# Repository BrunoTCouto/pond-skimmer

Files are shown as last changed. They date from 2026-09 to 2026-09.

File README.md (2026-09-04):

<h1 align="center">pond-skimmer</h1>

<p align="center">
  Skimmer de lago impresso em 3D para cano de PVC de esgoto de <b>150 mm</b>,<br>
  com <b>barreira de peixes de 3 mm</b>, cesto removível e vazão de verdade.<br>
  100% gerado por script paramétrico em Python — sem CAD manual.
</p>

<p align="center">
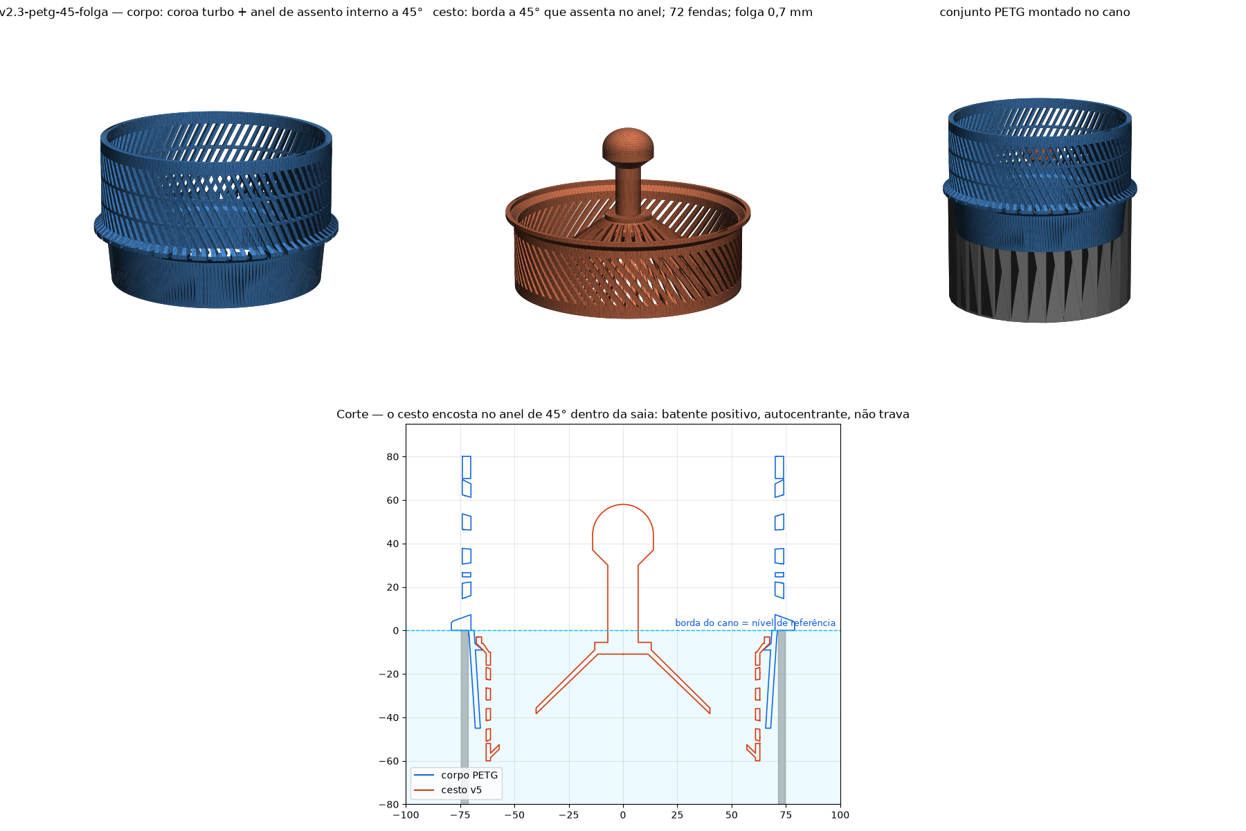
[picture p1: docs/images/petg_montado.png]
v2.3: corpo PETG + cesto montados no cano
  <br>
  <sub><b>v2.3</b> (atual) — corpo com anel de assento interno a 45° e cesto de 72 fendas. z = 0 é a borda do cano. Figuras geradas dos STLs por <code>tools/render.py</code>.</sub>
</p>

<p align="center">
  <a href="#-começando">Começando</a> ·
  <a href="#-como-funciona">Como funciona</a> ·
  <a href="#-peças-e-versões">Peças e versões</a> ·
  <a href="#-impressão">Impressão</a> ·
  <a href="#-instalação-e-uso">Instalação</a> ·
  <a href="#-a-física-em-um-parágrafo">A física</a> ·
  <a href="#-modificar-e-regenerar">Modificar</a> ·
  <a href="docs/DISCOVERY.md">Discovery</a> ·
  <a href="CHANGELOG.md">Changelog</a>
</p>

---

## 🚀 Começando

Quer só imprimir? Pegue o **par** de uma pasta em `stl/` — corpo e cesto de
versões diferentes **não** encaixam.

| Quero… | Pasta | Arquivos | Material |
|---|---|---|---|
| a versão definitiva (atual) | [`stl/v2.3-petg-45-folga/`](stl/v2.3-petg-45-folga/) | `corpo150_v2.3.stl` + `cesto150_v2.3.stl` | PETG |
| reproduzir o que está no lago hoje | [`stl/v1.0-instalado/`](stl/v1.0-instalado/) | `corpo150_turbo.stl` + `cesto150_v3.stl` | ABS + PLA |

Configurações de impressão em [Impressão](#-impressão). Nenhuma peça usa
suporte.

## 💧 Como funciona

O cano de 150 mm é o dreno do lago: o nível da água fica na borda dele. O
skimmer encaixa **por dentro** do cano e apoia um aro na borda — nada sobe o
nível por construção. Acima da borda fica uma coroa ranhurada; dentro do
cano, um cesto removível.

```
                    ┌───────── coroa: 80 fendas × 3 mm, 80 mm ─────────┐
                    │  ~55% do perímetro aberto = 250 mm de vertedouro │
  lago ──► fendas ──┼──► cai no cesto ──► fendas de 2 mm ──► cano ──► bomba
                    │     (parede + fundo em cone)                     │
  ═══════ nível ≈ borda + 3 cm ═════════════════════════════════════════
                    └── aro apoiado na borda · saia Ø136→142 centraliza ──┘
```

- **Peixe**: o vão de 3 mm da coroa barra tudo que não seja alevino. O que
  passa (≤ 3 mm) cai num cesto de fendas de **2 mm** — fica preso **vivo**
  até a limpeza, em vez de seguir pro rotor da bomba.
- **Folhas e sujeira**: ficam na coroa (fendas diagonais soltam detrito) ou
  no cesto. Limpar = puxar o cesto pelo botão.
- **Nível**: definido pelo perímetro aberto na linha d'água, e só por ele.
  Com a bomba do lago (~2–3 L/s) o nível fica ~3 cm acima da borda, contra
  ~2 cm do cano nu. Ver [a física](#-a-física-em-um-parágrafo).

## 📦 Peças e versões

Os STLs vivem em **pastas por versão — uma por pedido, imutáveis**; cada
pasta é um conjunto fechado, com README próprio. Visão geral em [`stl/README.md`](stl/README.md), detalhes em
[`CHANGELOG.md`](CHANGELOG.md), e o que está fisicamente instalado (com
SHA-256) em [`docs/IMPRESSO.md`](docs/IMPRESSO.md).

| Versão | Corpo | Cesto | Como o cesto se apoia | Status |
|---|---|---|---|---|
| **v2.3** `stl/v2.3-petg-45-folga/` | coroa turbo + **anel de assento a 45°** interno | borda a 45°, **72 fendas** de 2 mm (43% aberta), colar com 0,7 mm de folga | borda encosta no anel: batente positivo, autocentra, não trava | **atual** — imprimir em PETG |
| v2.0 → v2.2 | idem (v2.2: prateleira reta) | 36 → 72 fendas; colar 0,2–0,6 → 0,7 mm | — | superadas; ver `stl/README.md` |
| **v1.0** `stl/v1.0-instalado/` | coroa turbo (chanfro no furo da saia) | **v3**: 3 pilares com abinha, 36 fendas | abinhas no topo da coroa | **no lago** (ABS + PLA), tag `v1.0-instalado` |
| v1.0 alternativa | — | **v4**: sem pilares | cone de 13° no chanfro da saia (trava, tipo cone Morse) | encaixa no corpo v1.0; não impresso |

<p align="center">
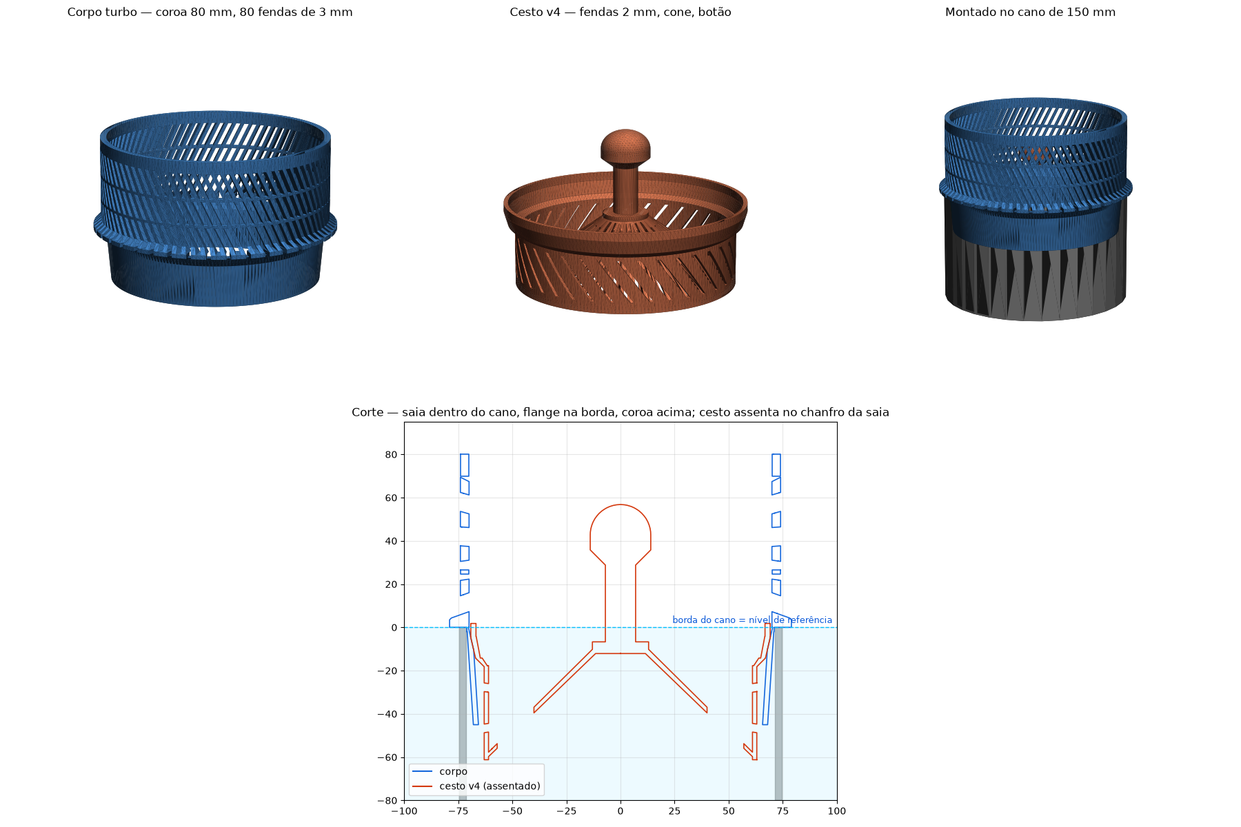
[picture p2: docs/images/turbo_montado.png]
v1.0 montado
  <br>
  <sub>v1.0 (o que está no lago): corpo turbo com chanfro no furo e cesto v4 no corte.</sub>
</p>

<p align="center">
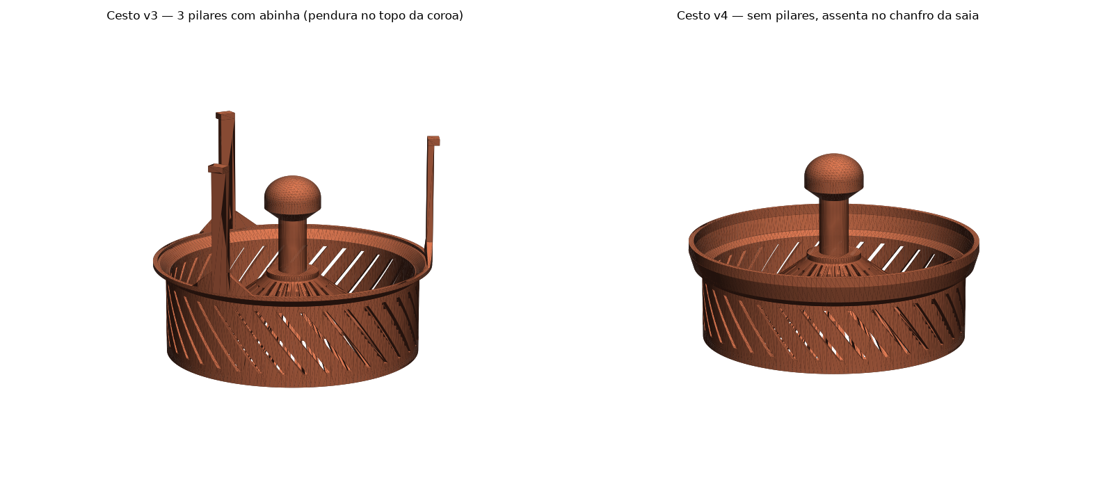
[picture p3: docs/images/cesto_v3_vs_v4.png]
cesto v3 vs v4
  <br>
  <sub>v1.0: cesto v3 (pilares com abinha, o que está impresso) e v4 (assenta no chanfro).</sub>
</p>

**O que é igual em todas**: coroa de 80 mm com 80 fendas de 3 mm inclinadas
a 20°, costelas de ~2,4 mm, parede de 4 mm, 2 anéis de travamento; saia
cônica Ø136→142 que entra no cano e centraliza; aro Ø158 apoiado na borda
com canais de entrada no nível da borda; cesto com fundo em cone "raios de
sol" (72 fendas de 2 mm) e botão central pra puxar.

## 🖨️ Impressão

| Peça | Orientação | Brim | Suporte | Perímetros | Notas |
|---|---|---|---|---|---|
| Corpo (qualquer versão) | **de cabeça pra baixo** — topo da coroa na mesa | 5 mm | **não** | ≥ 3 | 80 torres finas de 2,4 mm: câmara fechada ajuda; os anéis de travamento amarram as torres. Na v2.x o anel de assento vira um balanço de 45° |
| Cesto (todas as versões) | **em pé** — fundo na mesa | 5 mm | **não** | 6 | cone a 45°, botão com cone de 45° sob a cabeça; abinhas do v3 têm 2,7 mm de balanço |

**Material**: PETG é o ideal (água + sol). ABS também é definitivo. PLA
aguenta semanas/meses em água de lago, mas é quebradiço — serve de
provisório. Se o slicer oferecer suporte automático, **recuse**: ele planta
árvores de 8 cm dentro do cesto pra segurar balanços de 2 mm.

## 🔧 Instalação e uso

1. **Corpo**: desce com a saia dentro do cano até o aro apoiar na borda. Sem
   fixação — a saia (Ø142 na borda) centraliza com 0,5–1,5 mm de folga.
2. **Cesto**: desce pelo centro da coroa. v2.x assenta a borda de 45° no anel
   interno (autocentra); v3 apoia as 3 abinhas no topo da coroa, em qualquer
   ângulo.
3. **Limpeza**: puxa o cesto pelo botão, sacode, volta. A coroa se limpa
   passando a mão; o corpo sai do cano só de levantar.
4. **Nível subindo com o tempo** = fendas entupindo. Com 30% tapadas o nível
   sobe ~25%.

## 📐 A física em um parágrafo

O cano nu é um vertedouro de 450 mm de perímetro. Tudo que se põe na boca
dele reduz o perímetro **aberto na linha d'água**, e é só isso que define o
nível: `Q ≈ 1,7 · L · h^1,5`. A primeira versão tinha fendas de 3 mm a cada
12 mm mais uma banda no cesto — sobraram 85 mm de vertedouro e a água subiu
mais de 55 mm, passando por cima. **Altura da coroa não ajuda** (fenda seca é
parede) e **grade é pior que fenda** (paga barra nas duas direções). O que
ajuda: costela mais fina (80 fendas, 2,4 mm) e tirar o que estiver atrás das
fendas (a banda do cesto). Resultado: ~250 mm de vertedouro.

<p align="center">
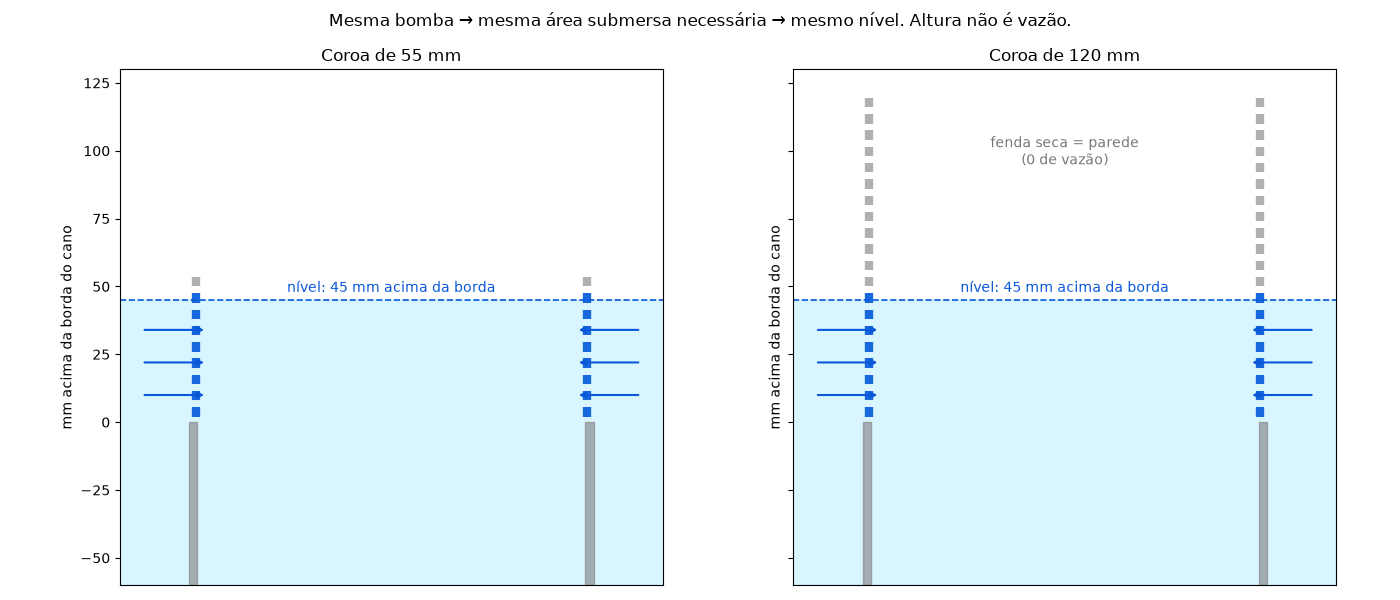
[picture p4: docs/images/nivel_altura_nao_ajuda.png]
altura não é vazão
  
</p>

A história completa, com os erros, está em [`docs/DISCOVERY.md`](docs/DISCOVERY.md).

## 🛠️ Modificar e regenerar

Tudo é gerado por [`scripts/skimmer150.py`](scripts/skimmer150.py) com
[`manifold3d`](https://github.com/elalish/manifold) + `trimesh`. As
dimensões são constantes no topo do arquivo; STL nunca é editado à mão.

```bash
python3 -m venv venv && ./venv/bin/pip install -r requirements.txt
./venv/bin/python scripts/skimmer150.py           # gera TODAS as pastas de stl/ (tabela VERSIONS no fim do script)
./venv/bin/python tools/check_fit.py stl/v2.3-petg-45-folga/corpo150_v2.3.stl stl/v2.3-petg-45-folga/cesto150_v2.3.stl
./venv/bin/python tools/render.py                 # figuras de docs/images
```

[`tools/check_fit.py`](tools/check_fit.py) é o que roda antes de qualquer
STL sair do repo: peça única e estanque, colisão cesto × corpo assentado e
durante a inserção, altura em que o cesto assenta, perímetro aberto na linha
d'água e um corte em PNG.

Regras que custaram impressões (detalhes no Discovery):

- `Manifold.cylinder(h, r_base, r_topo)` — cone invertido foi o bug mais repetido.
- `CrossSection` sempre **anti-horário**; horário vira furo e o manifold sai vazio.
- Sólidos que só se tocam num plano não se fundem: sempre um anel de solda.
- Corte inclinado precisa ir fundo pra cobrir a parede curva — e depois ser
  **confinado** ao anel da parede, senão morde o cone do fundo.
- Anel apoiado em pilares = anel no ar = não imprime.
- Toda peça nova passa pelo `check_fit.py` contra o corpo do **par**.

## 🗂️ Layout do repo

```
scripts/skimmer150.py     fonte de verdade; tabela VERSIONS = uma pasta por versão
stl/<versão>/             STLs gerados + README do conjunto (pastas imutáveis)
tools/check_fit.py        verificação de encaixe e vazão
tools/render.py           figuras de docs/images a partir dos STLs
docs/DISCOVERY.md         diário: hidráulica, peixes, CSG, impressão
docs/IMPRESSO.md          o que está no lago, com SHA-256
CHANGELOG.md              versões
CLAUDE.md                 regras pra sessões de Claude Code
```

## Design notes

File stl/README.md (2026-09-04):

# STLs por versão

**Uma pasta por pedido, e pasta é imutável.** Cada mudança — por menor que
seja — vira uma pasta nova; a anterior fica exatamente como estava. Assim
qualquer STL que já foi baixado ou impresso continua rastreável. A versão
mais recente é a que o README principal mostra.

Corpo e cesto de uma pasta encaixam **entre si**. Não misture pastas.

| Pasta | O que mudou | Corpo | Cesto | Status |
|---|---|---|---|---|
| [`v1.0-instalado/`](v1.0-instalado/) | corpo turbo (80 fendas, coroa 80 mm) + cesto v3 em pilares | `corpo150_turbo.stl` | `cesto150_v3.stl` (`cesto150_v4.stl` também encaixa) | **no lago** — ABS + PLA |
| [`v2.0-petg/`](v2.0-petg/) | primeiro conjunto PETG: anel de assento a 45° dentro da saia; cesto sem pilares | `corpo150_v2.0.stl` | `cesto150_v2.0.stl` — 36 fendas, colar Ø136 | superada |
| [`v2.1-petg-72fendas/`](v2.1-petg-72fendas/) | fendas da parede do cesto 36 → **72** | `corpo150_v2.1.stl` | `cesto150_v2.1.stl` — 72 fendas, colar Ø136 | superada |
| [`v2.2-petg-prateleira/`](v2.2-petg-prateleira/) | assento vira prateleira reta de 2,2 mm com 60° embaixo; colar com folga 0,7 mm | `corpo150_v2.2.stl` | `cesto150_v2.2.stl` — colar reto Ø135 | superada (dono preferiu o 45°) |
| [`v2.3-petg-45-folga/`](v2.3-petg-45-folga/) | volta o anel de 45°, mantém a folga de 0,7 mm no colar | `corpo150_v2.3.stl` | `cesto150_v2.3.stl` — 72 fendas, colar Ø135 | **atual** — imprimir em PETG |

Comum a todas: coroa de 80 mm com 80 fendas de 3 mm, saia Ø136→142 dentro do
cano, aro na borda; cesto com fendas de 2 mm, fundo em cone e botão.

Como nasce cada arquivo: `python scripts/skimmer150.py` gera **todas** as
pastas a partir da tabela `VERSIONS` no fim do script (ou
`python scripts/skimmer150.py v2.3-petg-45-folga` pra uma só). STL nunca é
editado à mão. Detalhes de cada versão no [CHANGELOG](../CHANGELOG.md); o que
está fisicamente instalado (com SHA-256) em [docs/IMPRESSO.md](../docs/IMPRESSO.md).

Cada pasta tem um `preview.png` (3 vistas 3D + corte com o cesto assentado),
gerado por `python tools/render.py` — é o que se olha antes de imprimir.

Antes de imprimir, confira o par:

```bash
python tools/check_fit.py stl/<pasta>/corpo*.stl stl/<pasta>/cesto*.stl
```

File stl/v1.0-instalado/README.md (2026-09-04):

# v1.0 — instalado no lago

| Arquivo | Peça | Material | Notas |
|---|---|---|---|
| `corpo150_turbo.stl` | corpo | **ABS**, impresso 2026-09-03 | coroa 80 mm, 80 fendas × 3 mm a 20°, parede 4 mm, 2 anéis, saia Ø136→142 com chanfro interno de 13°. **Não alterar**: é a referência de encaixe dos cestos desta pasta |
| `cesto150_v3.stl` | cesto | **PLA** (provisório), impresso 2026-09-04 | 3 pilares 8×3 mm com abinha no topo da coroa; 36 fendas × 2 mm; fundo em cone; botão |
| `cesto150_v4.stl` | cesto (alternativa) | não impresso | assenta no chanfro de 13° da saia, nada acima da borda; o cone raso trava — funciona, mas pede um puxão pra sair |

Impressão: corpo de cabeça pra baixo com brim; cestos em pé com brim; sem
suporte; ≥3 perímetros (6 no cesto).

SHA-256 dos arquivos impressos em [docs/IMPRESSO.md](../../docs/IMPRESSO.md).
Tag git: `v1.0-instalado`.

## Preview

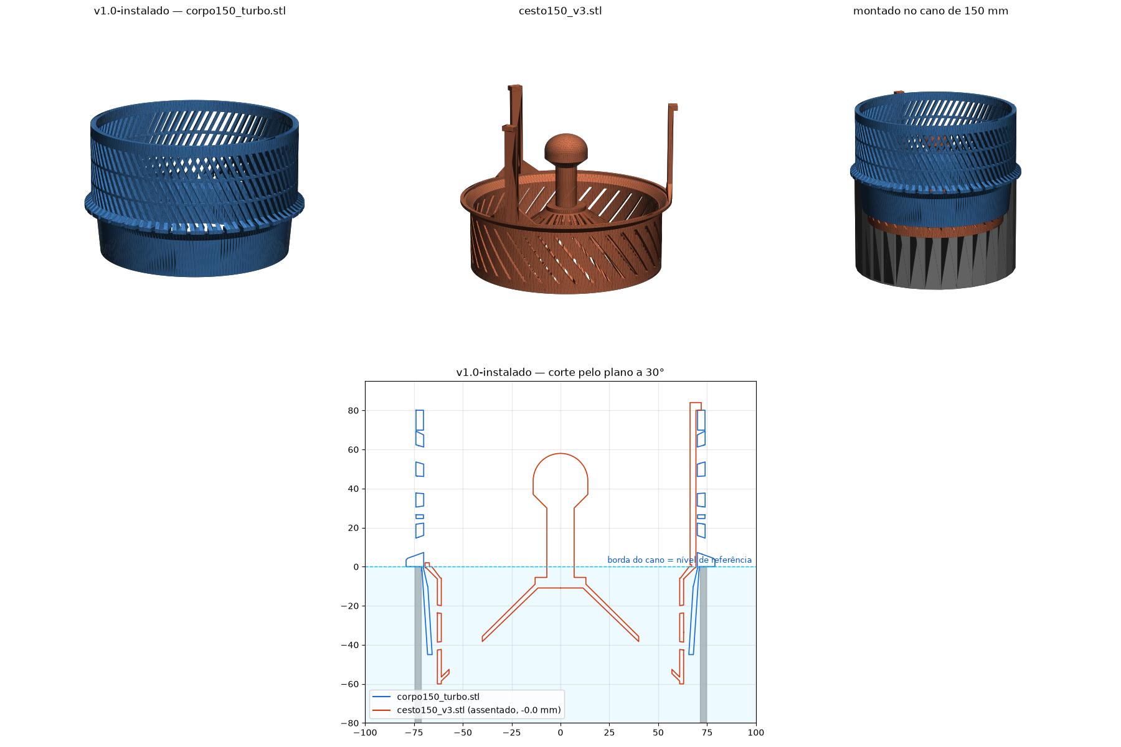
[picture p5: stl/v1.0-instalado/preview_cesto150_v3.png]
corpo + cesto v3


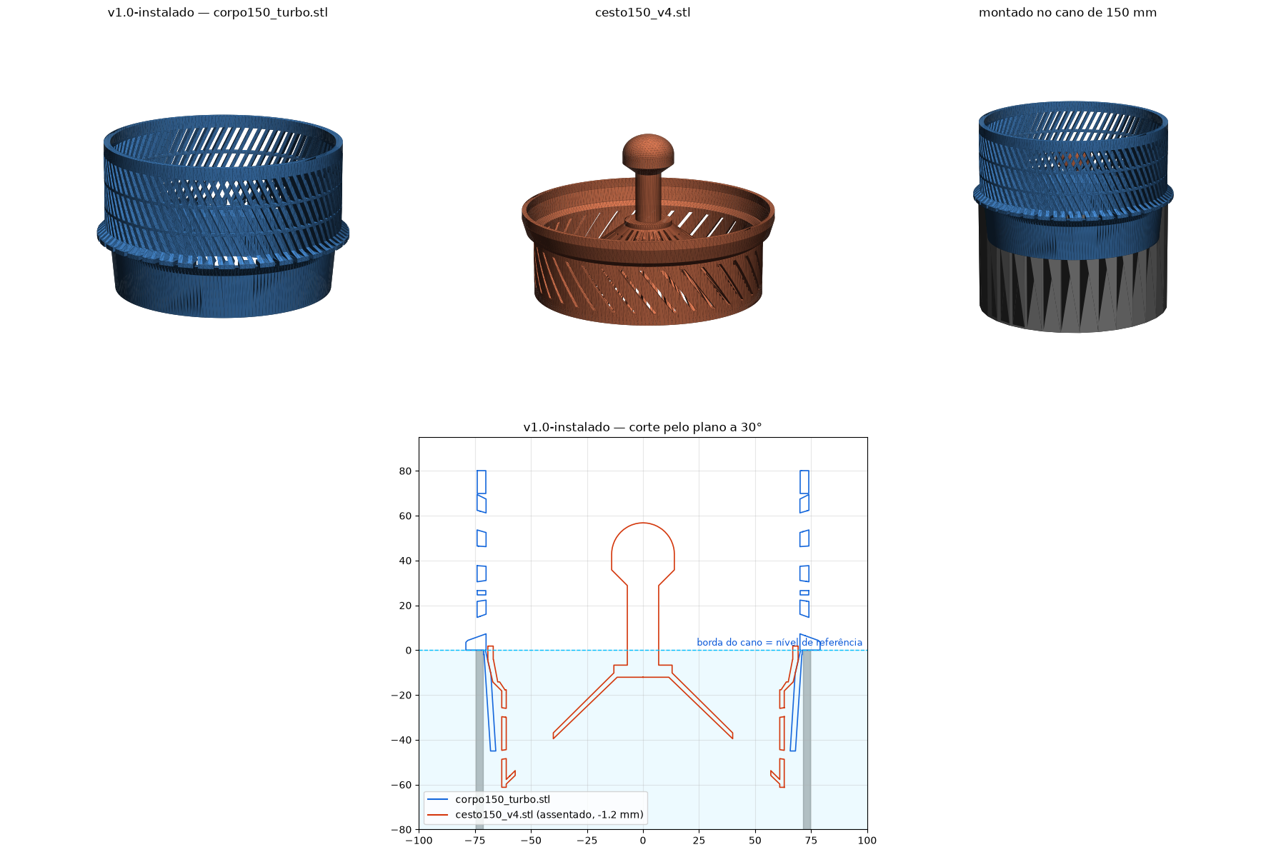
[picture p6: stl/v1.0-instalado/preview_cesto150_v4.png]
corpo + cesto v4


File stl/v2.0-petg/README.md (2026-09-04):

# v2.0-petg — primeiro conjunto PETG (superada)

Pedido: "fazer todos os modelos novos, preparar tudo pro PETG" — corpo com
suporte interno pro cesto em vez de pilares.

| Arquivo | Peça | Notas |
|---|---|---|
| `corpo150_v2.0.stl` | corpo | coroa turbo da v1.0 + **anel de assento a 45°** dentro da saia (z −9 a −4,8; r 64,5 → 68,7); sem o chanfro do furo |
| `cesto150_v2.0.stl` | cesto | borda a 45° que assenta no anel; colar Ø136 (folga de só 0,2–0,6 mm no furo — corrigido na v2.2+); **36 fendas** de 2 mm; fundo em cone; botão |

Só encaixam um no outro. Superada por [`v2.1-petg-72fendas`](../v2.1-petg-72fendas/).

## Preview

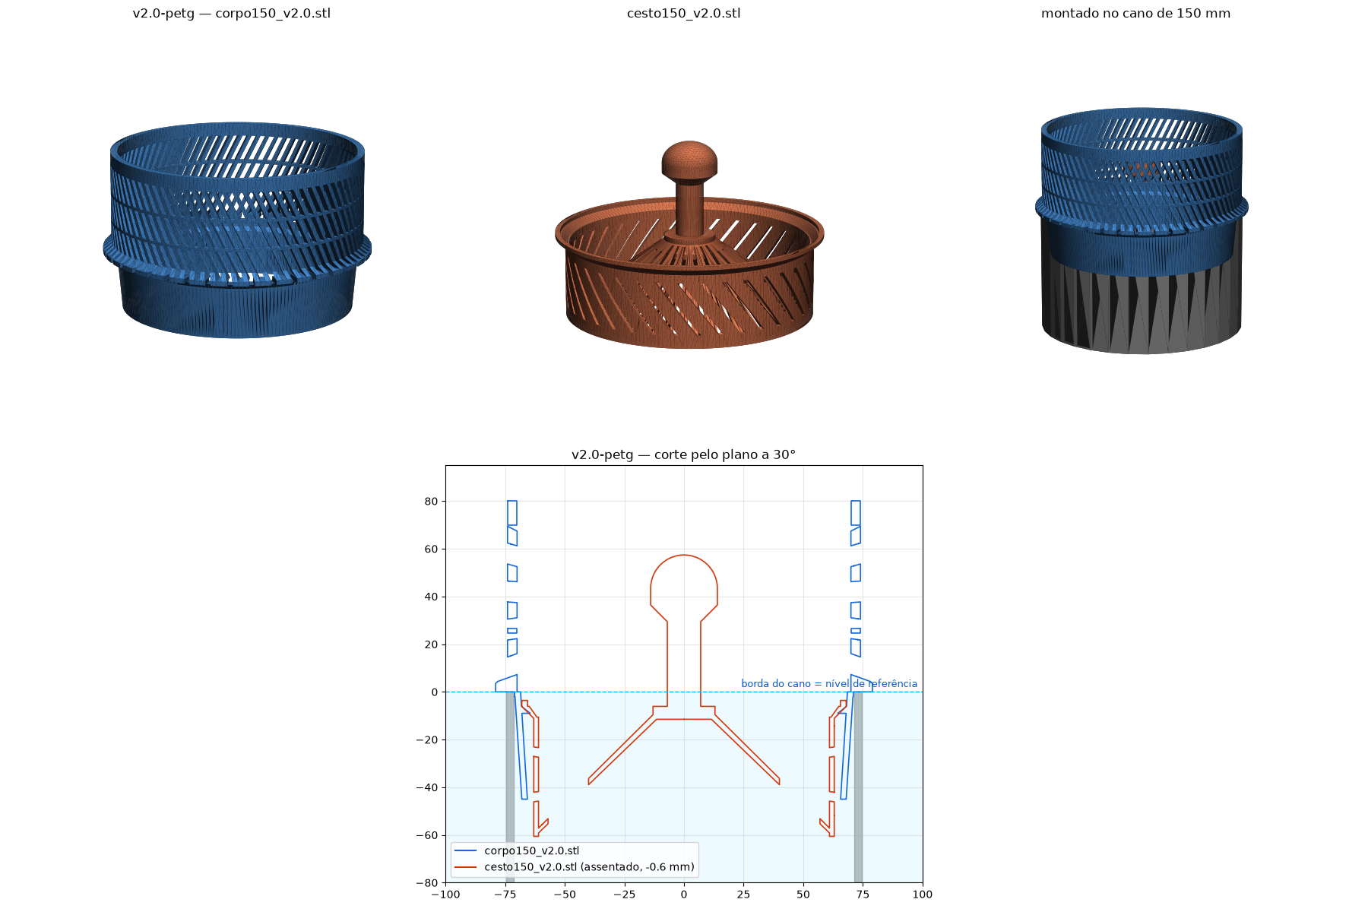
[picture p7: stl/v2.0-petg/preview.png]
preview


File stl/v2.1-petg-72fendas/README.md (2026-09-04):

# v2.1-petg-72fendas — mais vãos na lateral do cesto (superada)

Pedido: "dá pra aumentar a quantidade de vãos na lateral do cesto, igual
fizemos no corpo?"

| Arquivo | Peça | Notas |
|---|---|---|
| `corpo150_v2.1.stl` | corpo | idêntico ao da v2.0 (anel de assento a 45°) |
| `cesto150_v2.1.stl` | cesto | fendas da parede **36 → 72** (costela ~3 mm, 43% aberta em vez de 21%); colar Ø136; resto igual à v2.0 |

Só encaixam um no outro. Superada por [`v2.2-petg-prateleira`](../v2.2-petg-prateleira/).

## Preview

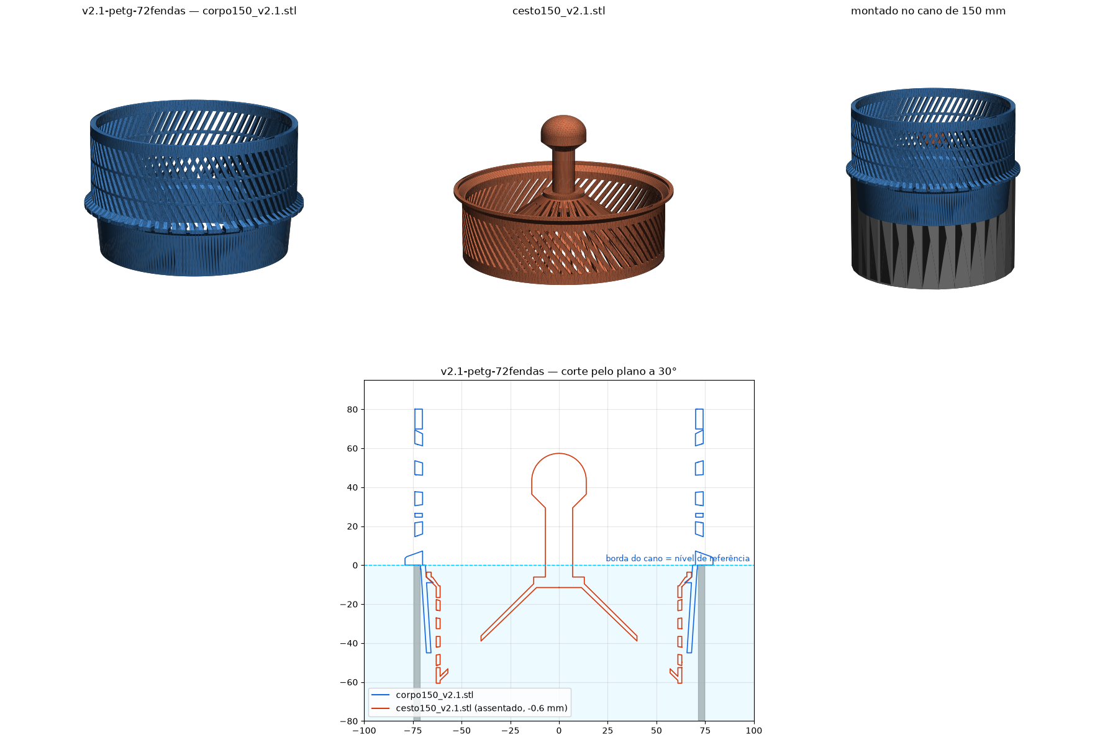
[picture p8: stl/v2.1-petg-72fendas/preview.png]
preview


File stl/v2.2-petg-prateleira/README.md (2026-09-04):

# v2.2-petg-prateleira — assento em prateleira reta (superada)

Pedido: "chanfro de suporte mais fácil de imprimir — parte de baixo sobe
inclinado, parte de cima reta". Também abriu a folga do colar.

| Arquivo | Peça | Notas |
|---|---|---|
| `corpo150_v2.2.stl` | corpo | coroa turbo + **prateleira** dentro da saia: topo reto em z −6 (2,2 mm), parte de baixo a 60° até a parede |
| `cesto150_v2.2.stl` | cesto | colar reto Ø135 (folga 0,7 mm) que apoia na prateleira; 72 fendas |

Funciona e imprime (o topo reto vira um balanço de uma camada de 2,2 mm na
impressão invertida). O dono preferiu voltar ao anel de 45°, que na
impressão de ponta-cabeça já era "base inclinada, topo reto".
Superada por [`v2.3-petg-45-folga`](../v2.3-petg-45-folga/).

## Preview

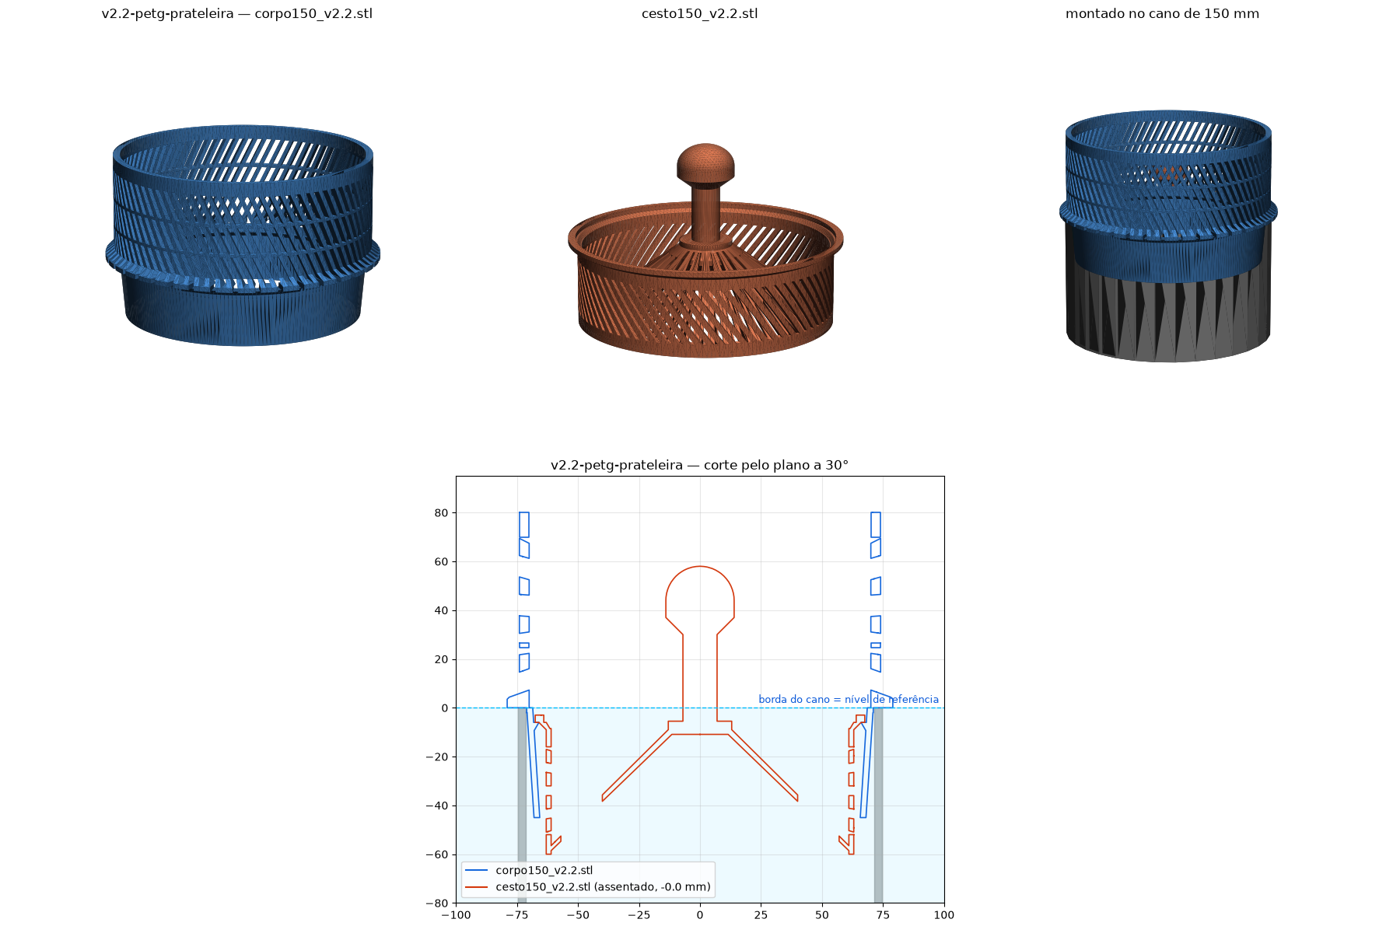
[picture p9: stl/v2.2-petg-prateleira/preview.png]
preview


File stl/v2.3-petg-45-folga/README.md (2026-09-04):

# v2.3-petg-45-folga — conjunto PETG atual

Pedido: "a versão de antes tava boa — fecha a versão boa". Anel de 45° de
volta, mantendo a folga de 0,7 mm no colar que a v2.2 trouxe.

| Arquivo | Peça | Notas |
|---|---|---|
| `corpo150_v2.3.stl` | corpo | coroa turbo (80 fendas × 3 mm, 80 mm, parede 4 mm, 2 anéis) + **anel de assento a 45°** dentro da saia (z −9 a −4,8; r 64,5 → 68,7); sem o chanfro do furo |
| `cesto150_v2.3.stl` | cesto | borda a 45° que assenta no anel (batente positivo, autocentrante, não trava); colar Ø135 com **0,7 mm de folga**; topo em z −3 (nada acima da borda do cano); **72 fendas** de 2 mm na parede (43% aberta); fundo em cone com 72 fendas; botão |

**Só encaixam um no outro.** O cesto não tem apoio no corpo da v1.0.

Impressão (PETG, Bambu P1S): corpo de cabeça pra baixo com brim — o anel de
assento vira um balanço de 45°; cesto em pé com brim, 6 perímetros; suporte
**desligado** nos dois.

Verificado: 1 corpo cada, 0 colisões assentado e em +20/+50 mm, assenta no
anel com 0,4 mm de acomodação, 52% do perímetro aberto (240 mm de vertedouro).

Ao instalar: atualizar `docs/IMPRESSO.md` e criar a tag `v2.3-instalado`.

## Preview

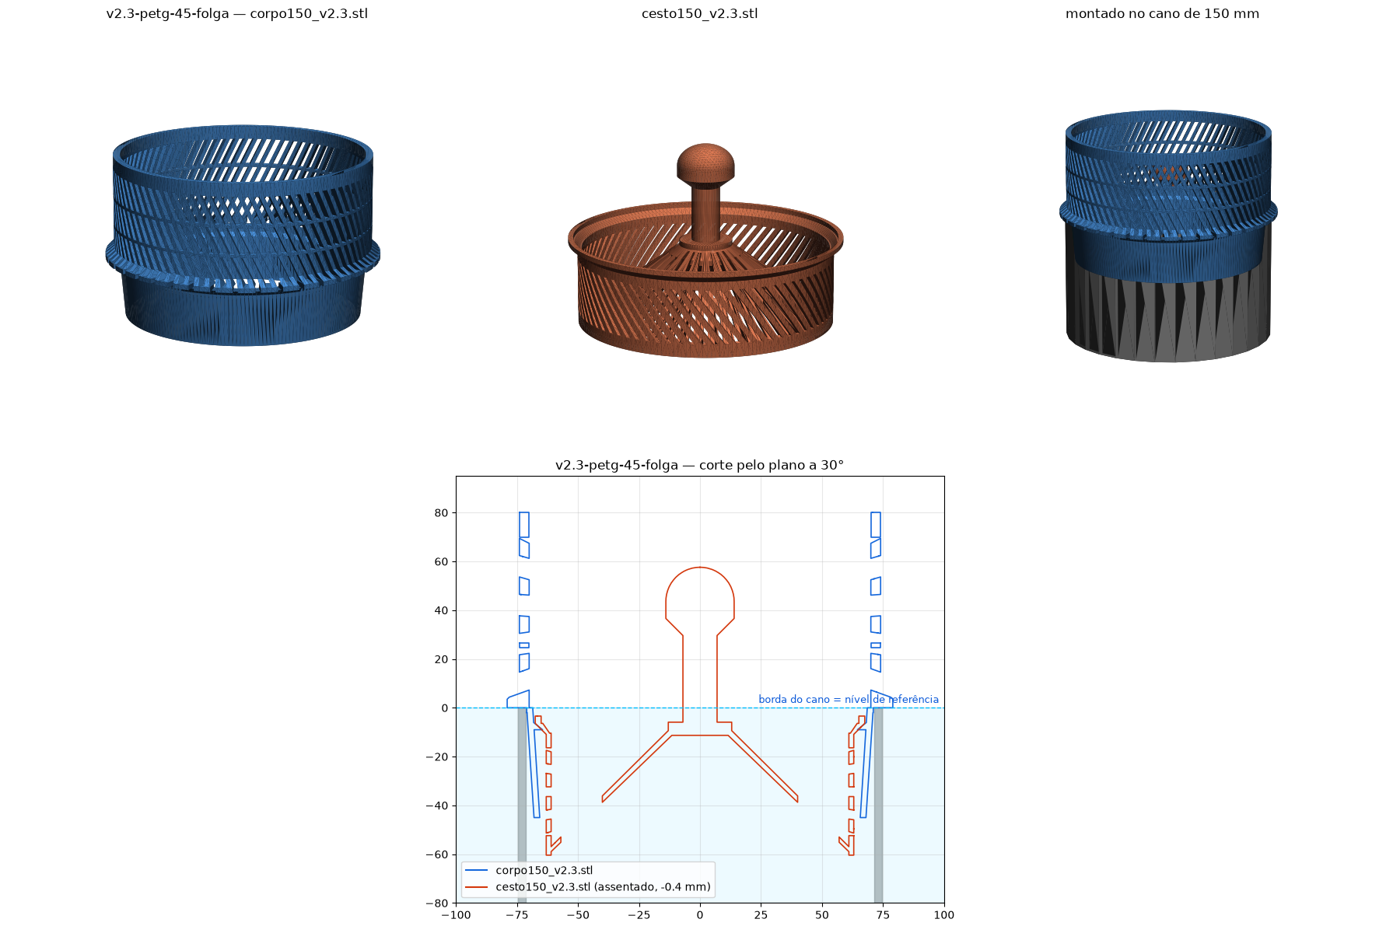
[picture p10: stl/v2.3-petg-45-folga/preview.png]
preview


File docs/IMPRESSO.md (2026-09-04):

# O que está instalado no lago

Nota de referência: se um dia precisar reimprimir **exatamente** o que está lá,
ou saber se um STL novo ainda encaixa, é isto aqui. Tag git: `v1.0-instalado`.

| Peça | Arquivo | Material | Impresso em | SHA-256 do STL |
|---|---|---|---|---|
| Corpo | `stl/v1.0-instalado/corpo150_turbo.stl` | ABS (Bambu P1S, 0.20 mm Strength, 6 paredes) | 2026-09-03 | `074b1c6b4e48bdd89bbbf02e807f4427c8351a55aac63afd9d6b18c8bbf55f60` |
| Cesto | `stl/v1.0-instalado/cesto150_v3.stl` | PLA genérico (provisório até o PETG) | 2026-09-04 | `d25568b3e3782798a476feef0245259df0fc708bc4a71bad1f325fb9b63d41ca` |

Conferir se o arquivo atual ainda é o impresso:

```bash
shasum -a 256 stl/v1.0-instalado/corpo150_turbo.stl stl/v1.0-instalado/cesto150_v3.stl
```

Se o hash mudou, o script foi alterado e o STL **não** é mais o que está no
lago — o par de referência continua sendo o hash acima (recuperável com
`git show v1.0-instalado:stl/v1.0-instalado/corpo150_turbo.stl > corpo_impresso.stl`).

## Observações de campo

- Cano: PVC esgoto, externo 149–151, interno 143–145, parede 3 mm.
- A saia (Ø142 na borda) entra com folga; a flange apoia na borda.
- Cesto v3 apoia pelas 3 abinhas no topo da coroa, em qualquer ângulo.
- Plano: substituir **as duas peças** pelo conjunto PETG atual
  (`stl/v2.3-petg-45-folga/`). Aí este arquivo deve ser atualizado (hashes
  novos) e uma tag `v2.3-instalado` criada.

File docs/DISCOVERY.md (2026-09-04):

# Discovery — o que aprendemos fazendo o skimmer

Diário das decisões, erros e medições do projeto, na ordem em que aconteceram.
Serve de memória pra quem (humano ou Claude) for mexer de novo.

## 1. Ponto de partida

- Arquivo: `Skimmer.3mf` do Bambu Studio, 2 plates (`Outside.STEP`,
  `Inside.STEP`), só malhas (150k/200k faces). Sem CAD paramétrico → não dá
  pra "mudar uma medida"; a saída foi remodelar do zero em Python.
- Medidas do original (extraídas da malha, eixo Y): luva Ø110 interna
  (~120 mm), cone Ø110→140 (50 mm), cesta ranhurada Ø140/146 (80 mm). Cesto
  interno Ø139,8 (folga 0,1 mm) com fendas que giram pra regular a abertura.
- Restrições do dono: cano de **150 mm** e **o nível da água não pode subir**
  da borda do cano. O original é um "pescoço" de 130 mm em cima do cano —
  incompatível com a segunda restrição.

## 2. Medidas do cano

- Externo "150" medido; interno **143–145**; parede **3 mm** (PVC esgoto).
- Saia de centragem: Ø136 na ponta → **Ø142 na borda**. Nunca pode chegar em
  143: se a saia calçar antes da flange apoiar, a peça fica suspensa e os
  canais de entrada sobem junto.

## 3. Hidráulica (a lição cara)

O cano nu é um vertedouro de **450 mm** de perímetro. Qualquer coisa que se
coloque em cima dele reduz o perímetro aberto na **linha d'água** — e é só
isso que define o nível:

    Q ≈ 1,7 · L · h^1,5     (vertedouro; L = perímetro aberto, h = lâmina)

- v1: fenda de 3 mm a cada 12 mm (25% aberto) × banda do cesto (79%) → L ≈
  **85 mm**. Com a bomba do lago (estimada em 2–3 L/s pela foto), h > 55 mm
  → passou por cima da coroa.
altura não é vazão

- Coisas que **não** mudam o nível: altura da coroa (fenda seca é parede),
  grade em vez de fenda (paga barra nas duas direções: 3×3 com barra de 2 =
  36% aberto, pior que fenda), formato do furo.
- Coisas que mudam: costela mais fina (limite de impressão ~2,4 mm), vão
  maior (passa peixe), perímetro maior.
- turbo: 80 fendas × 3 mm, costela 2,4 mm, sem banda → 54% → L ≈ **248 mm**.
  Estimativa: h ≈ 28 mm a 2 L/s, 37 mm a 3 L/s (cano nu: 19 / 25 mm).
- Entupimento: com 30% das fendas tapadas h sobe ~25%. Limpar a coroa faz
  parte.
- Qualquer barreira de 3 mm sempre pede alguns mm de lâmina a mais que o
  cano aberto — é o preço da barreira de peixes.

## 4. Peixes

- O que barra peixe é a **menor dimensão** do vão, não a inclinação.
- Fendas diagonais valem por outro motivo: soltam detrito (nada fica
  entalado em pé) e são ~15% mais compridas → deu pra estreitar 5→3 mm sem
  perder área.
- Cesto com fendas de 2,5 mm atrás de uma coroa de 3 mm retém só a faixa
  2,5–3: quase nada. Um alevino que passou pela coroa seguia pro cano → bomba.
  **Regra: fendas do cesto (2 mm) menores que o gate da coroa (3 mm)** —
  tudo que entra fica no cesto, vivo, até a limpeza.
- Peixe no cesto não asfixia (água corrente), mas apanha da queda d'água e
  seca se a bomba desligar. Não é lugar de peixe.

## 5. CSG com manifold3d — pegadinhas que custaram iterações

1. `Manifold.cylinder(h, r_baixo, r_topo)`: a ordem é **base → topo**. Cone
   invertido aconteceu **três vezes** (saia, transição do cesto, e num
   terceiro cone). Sintoma: peça em vários corpos ou dimensões espelhadas.
2. Dois sólidos que se tocam só num plano (z=0) **não viram um corpo**:
   `split()` do trimesh mostra 2 shells. Sempre um "anel de solda" com
   sobreposição volumétrica (ex.: `tube(71.5, 70.2, -2, 3.5)` entre saia e
   flange).
3. Corte inclinado (fenda diagonal) numa parede cilíndrica: a caixa reta
   deriva tangencialmente e precisa começar bem pra dentro (r=50–58) pra cobrir
   a parede curva nos extremos. Aí ela **morde** o que estiver dentro (o cone
   do fundo). Solução: `cortes ^ tube(anel da parede)`.
4. Chanfro embaixo da aba do cesto colidia com o topo da coroa. Flat-on-flat
   com balanço de ≤2,7 mm imprime bem; não vale chanfro.
5. Reforço triangular plano num furo redondo: as pontas passam do raio do
   furo (r 71,6 > 70). Clipar com `^ tube(69.3, ...)`.
6. Verificação que sempre roda antes de entregar: `split()` = 1 corpo;
   `contains()` do corpo sobre os vértices do cesto em 0/+20/+50 mm de
   inserção = 0; perímetro aberto amostrado em grade (θ, z) nas duas paredes
   em série; corte (r, z) plotado com o cano sobreposto.

## 6. Impressão

- Corpo: de cabeça pra baixo (topo da coroa na mesa) com chanfro de 45° entre
  coroa e flange pra não haver balanço horizontal. 80 torres de 2,4 × 4 mm:
  os 2 anéis de travamento existem pra amarrar as torres na impressão, não
  só pra rigidez.
- Cesto: em pé. Cone do fundo a 45°, botão com cone de 45° sob a cabeça.
- **Anel apoiado em 4 pilares = anel no ar** entre os pilares (~100 mm sem
  apoio). Não imprime; suporte em árvore de 8 cm dentro do cesto é ridículo.
  → v3: cada pilar termina na sua própria abinha; 3 pilares (assenta sem
  balançar, 5% de bloqueio).
- v4 elimina os pilares: o cesto assenta num cone de 13° que casa com o
  chanfro interno da saia (r 68 @ z-10 → 70,3 @ z0). Desce ~1,3 mm e trava
  com contato de área; nada acima da borda. Encaixa no corpo impresso, mas o
  cone raso **trava** (tan 13° < atrito → efeito cone Morse): sai com um puxão.
- Conjunto PETG (v2.0): o corpo ganha um **anel de assento a 45°** dentro da
  saia (fundo reto, face de cima a 45° subindo até o furo). Como o corpo
  imprime de ponta-cabeça, na impressão o anel cresce pra dentro a 45° e
  termina reto — "parte de baixo inclinada, topo reto", exatamente o que uma
  impressora gosta. O cesto v5 tem borda a 45° casada: autocentra, batente
  positivo, não trava; colar com 0,7 mm de folga no furo da saia (o primeiro
  rascunho tinha 0,2–0,6 mm — apertado demais pra PETG). Parede do v5 com 72
  fendas (43% aberta) em vez de 36. Só encaixa nesse corpo.
- Chegamos a trocar por uma prateleira reta de 2,2 mm com 60° embaixo; era
  equivalente, e o dono preferiu voltar ao 45° original.
- Pegadinha nova de CSG: polígono de `CrossSection` em sentido **horário** é
  lido como furo → o `revolve` sai vazio e a união inteira vira um manifold
  inválido (bbox `None`). Sempre CCW no plano (r, z).
- Materiais: ABS e PETG são definitivos em água. PLA dura semanas/meses (só
  amolece >55 °C), mas é quebradiço.
- Bambu Studio com suporte automático planta árvores pras abinhas de 2,7 mm.
  Deixar **desligado**.

## 7. Ambiente

- OpenSCAD não instalado; `manifold3d` + `trimesh` no venv resolvem tudo,
  inclusive booleans robustos e `section()` pra cortes.
- `trimesh.section` precisa de `scipy`, `shapely`, `networkx`, `rtree`;
  `proximity.signed_distance` é lento — `contains()` com amostragem `[::4]`
  basta.
- macOS não tem `timeout`.
- O sandbox do Claude Code barra `cp` para `~/Downloads` e SSH pro GitHub;
  entregar via SendUserFile e usar HTTPS (`gh auth`).
- O scratchpad é volátil: foi apagado uma vez e o script teve que ser
  reconstruído. **Por isso existe este repo.**

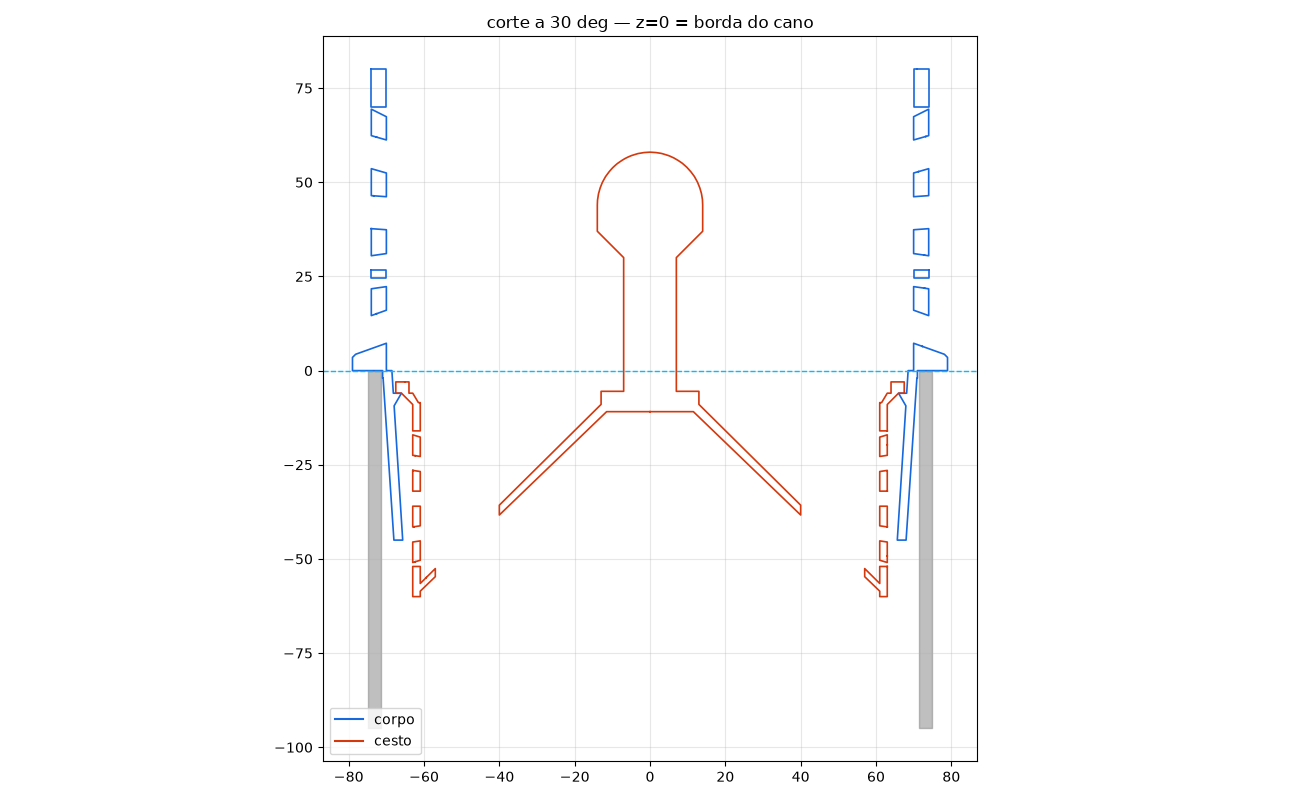
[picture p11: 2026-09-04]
docs/images/check_v2.2-petg-prateleira.png

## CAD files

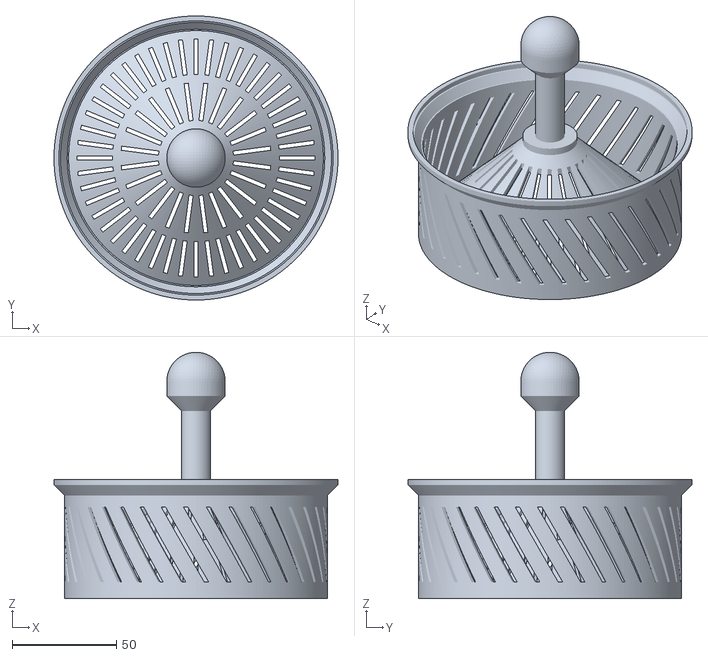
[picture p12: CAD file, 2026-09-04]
stl/v2.0-petg/cesto150_v2.0.stl
136.0 x 136.0 x 118.0

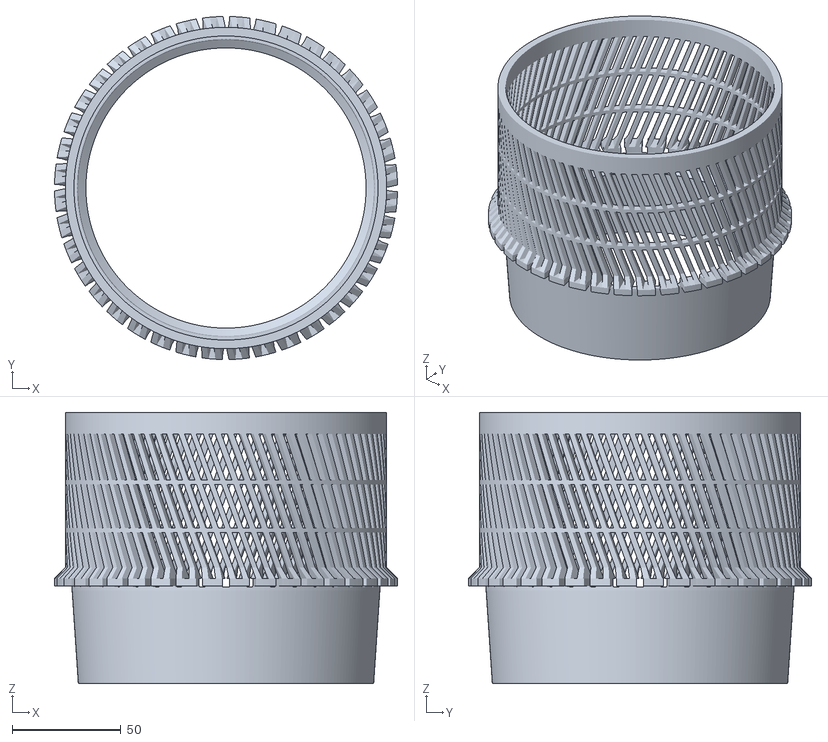
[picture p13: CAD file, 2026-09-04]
stl/v2.1-petg-72fendas/corpo150_v2.1.stl
158.0 x 158.0 x 125.0

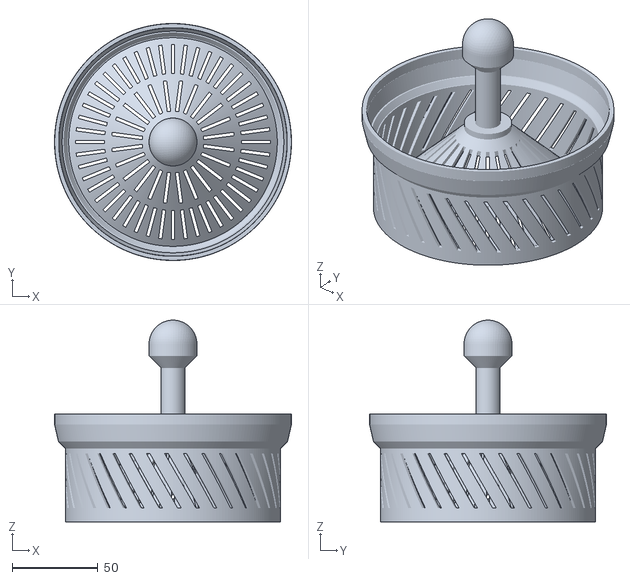
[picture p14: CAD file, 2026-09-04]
stl/v1.0-instalado/cesto150_v4.stl
138.6 x 138.6 x 118.0

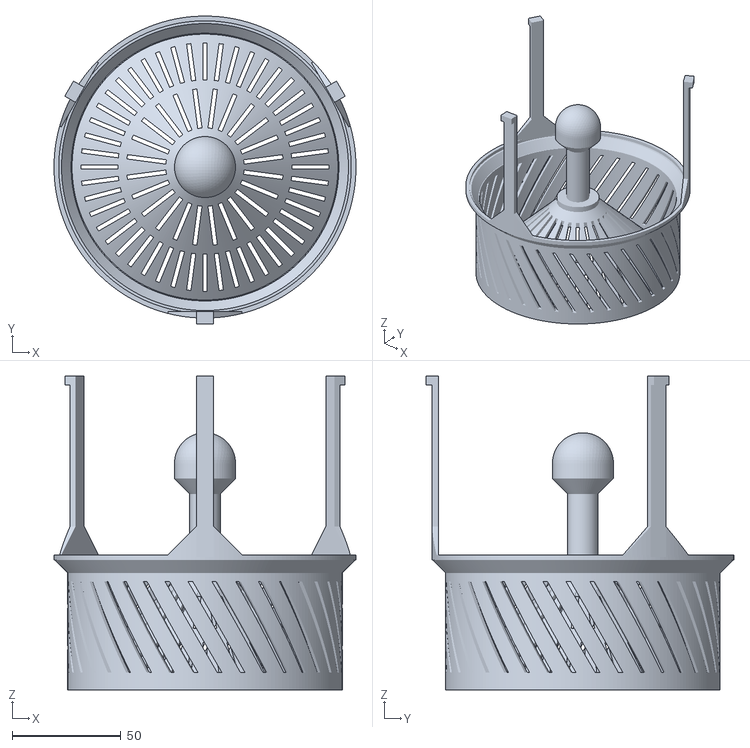
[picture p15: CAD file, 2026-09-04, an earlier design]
stl/v1.0-instalado/cesto150_v3.stl
138.6 x 141.3 x 144.0

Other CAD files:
stl/v2.2-petg-prateleira/cesto150_v2.2.stl
stl/v2.3-petg-45-folga/cesto150_v2.3.stl
stl/v2.1-petg-72fendas/cesto150_v2.1.stl
stl/v2.2-petg-prateleira/corpo150_v2.2.stl
stl/v1.0-instalado/corpo150_turbo.stl

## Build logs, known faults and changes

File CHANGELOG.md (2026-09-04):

# Changelog

Uma pasta em `stl/` por pedido do dono; **pasta é imutável** — mudança nova é
versão nova. Tags git marcam o que foi impresso e instalado; o que está
fisicamente no lago está em [docs/IMPRESSO.md](docs/IMPRESSO.md).

## v2.3-petg-45-folga — atual (não impressa ainda) — 2026-09-04

"A versão de antes tava boa — fecha a versão boa." Volta o anel de assento a
45° da v2.0/v2.1, mantendo a folga de 0,7 mm no colar que veio da v2.2.
`corpo150_v2.3.stl` + `cesto150_v2.3.stl` (72 fendas, colar Ø135).
Verificação: 1 corpo cada, 0 colisões em 0/+20/+50 mm, 0,4 mm de acomodação
no anel, 52% do perímetro aberto (240 mm de vertedouro equivalente).

## v2.2-petg-prateleira — 2026-09-04

"Chanfro de suporte mais fácil de imprimir: parte de baixo sobe inclinado,
parte de cima reta." Assento vira prateleira reta de 2,2 mm com 60° embaixo;
cesto com colar reto Ø135 (folga 0,7 mm — a v2.0/v2.1 tinham 0,2–0,6, apertado
pra PETG). Imprime; na orientação invertida é equivalente ao 45°. Superada.

## v2.1-petg-72fendas — 2026-09-04

"Dá pra aumentar a quantidade de vãos na lateral do cesto?" Fendas da parede
do cesto 36 → 72 (43% aberta, o dobro). Corpo igual à v2.0.

## v2.0-petg — 2026-09-04

"Fazer todos os modelos novos, preparar tudo pro PETG." Corpo com **anel de
assento a 45° dentro da saia** (z −9 a −4,8; r 64,5 → 68,7), sem o chanfro do
furo; cesto sem pilares, borda a 45° que assenta no anel, 36 fendas, colar
Ø136. Motivação: o cone de 13° do v4 trava (cone Morse); o anel de 45° é um
batente que autocentra e solta fácil.

## v1.0-instalado — tag `v1.0-instalado` — 2026-09-03/04

O que está no lago.

- `corpo150_turbo.stl` — ABS. Coroa 80 mm, 80 fendas de 3 mm a 20°, costelas
  ~2,4 mm, parede 4 mm, 2 anéis de travamento, canais na borda a cada 2
  fendas, saia Ø136→142 com chanfro interno de 13° no furo.
- `cesto150_v3.stl` — PLA (provisório). 3 pilares 8×3 com abinha no topo da
  coroa e reforço de 45° na base; 36 fendas de 2 mm; fundo em cone; botão.
- `cesto150_v4.stl` — também encaixa nesse corpo (assenta no chanfro de 13°;
  nunca impresso — o cone raso trava).

## v0 — original (superada, arquivos não preservados)

Coroa de 55 mm com 36 fendas de 3 mm + banda giratória no cesto. Impressa; a
água passou por cima (vertedouro equivalente ~85 mm). Lição em
`docs/DISCOVERY.md`.

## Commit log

2026-09-04 Pond skimmer for a 150 mm PVC pipe: parametric scripts, STLs and discovery log
    - scripts/skimmer150.py: printed corpo (turbo: 80 x 3 mm slots, 80 mm crown,
    bracing rings) + cesto v3 (posts, printed in PLA) + cesto v4 (bevel seat,
    for the PETG reprint)
    - scripts/skimmer150_v2.py: plan B "fish fence" around the pipe
    - tools/check_fit.py: body/collision/seating/open-perimeter check + section PNG
    - docs/DISCOVERY.md: hydraulics, fish gate, CSG pitfalls, print lessons
    - CLAUDE.md: working rules for future sessions
    [cesto150_v2.stl, cesto150_v3.stl, cesto150_v4.stl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]
2026-09-04 docs: schematic renders instead of the photo; tools/render.py regenerates them from the STLs
2026-09-04 v2.0 PETG set, versioned STL folders, changelog and installed-parts note; drop plan B
    - corpo150_petg: turbo crown + internal 45-deg seat ledge in the skirt (no bore bevel)
    - cesto150_v5: 45-deg flare seats on the ledge (positive stop, no self-lock),
    72 x 2 mm wall slots (43% open, 2x v3/v4), top at z -3
    - stl/ split into v1.0-instalado (printed: ABS corpo + PLA cesto v3, + v4) and
    v2.0-petg; READMEs per folder; script exports straight into them
    - CHANGELOG.md; docs/IMPRESSO.md pins the printed STLs by SHA-256
    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
    [cesto150_v2.stl, cesto150_v3.stl, cesto150_v4.stl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]
2026-09-04 docs: DISCOVERY — drop stale v2 reference, describe v4 self-lock and the v2.0 PETG seat
2026-09-04 v2.0: shelf seat (flat 2.2 mm top, 60-deg underside) + wider collar clearance; README polish
    - corpo150_petg: ledge is now a flat shelf at z -6 with a 60-deg underside,
    printable upside-down as a one-layer 2.2 mm overhang (like the v3 tabs)
    - cesto150_v5: flat collar underside rests on the shelf; collar OD 135
    (0.7 mm clearance to the skirt bore, was 0.2-0.6); seating drop 0.0 mm
    - CrossSection winding lesson (CW = hole = empty manifold) in DISCOVERY/CLAUDE.md
    - README rewritten: quick start, how it works, versions table, print table,
    physics, repo layout; figure titles updated
    [cesto150_v5.stl, corpo150_petg.stl]
2026-09-04 v2.0: back to the 45-deg seat ring (owner's call), keep the 0.7 mm collar clearance; README leads with the latest version
    [cesto150_v5.stl, corpo150_petg.stl]
2026-09-04 Immutable version folders: one per owner request (v2.0 .. v2.3), VERSIONS table in the script
    - scripts/skimmer150.py: build_corpo_petg(seat) / build_cesto_v5(seat, collar_r, n_fine)
    + frozen VERSIONS table; LATEST = v2.3-petg-45-folga; `skimmer150.py <folder>` builds one
    - stl/: v2.0-petg (45-deg seat, 36 slots), v2.1-petg-72fendas, v2.2-petg-prateleira
    (flat shelf), v2.3-petg-45-folga (current) — each with its own README; v1.0 untouched
    (hashes verified)
    - check_fit run on all four PETG pairs (0 collisions each); render.py follows LATEST
    - CHANGELOG per version; CLAUDE.md: folders are immutable, README always shows LATEST
    [cesto150_v2.0.stl, cesto150_v2.1.stl, cesto150_v2.2.stl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]
2026-09-04 Per-version preview.png (3 shaded views + seated cross-section) in every stl/ folder
    render.py iterates VERSIONS from the script and seats the basket using
    check_fit.seating_drop; v1.0 gets one preview per compatible basket (v3, v4).
    Folder READMEs embed the images; rule documented in stl/README and CLAUDE.md.
2026-09-04 README: drop the credit section — the design was rebuilt from scratch
